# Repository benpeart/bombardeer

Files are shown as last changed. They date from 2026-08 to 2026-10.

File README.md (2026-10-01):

# Bombardeer Wildlife Deterrent Turret: System Architecture Specification

**Bombardeer** is an open-source, vision-guided autonomous deterrent turret designed to protect outdoor spaces, gardens, orchards, and agricultural property from intrusive wildlife (such as deer).

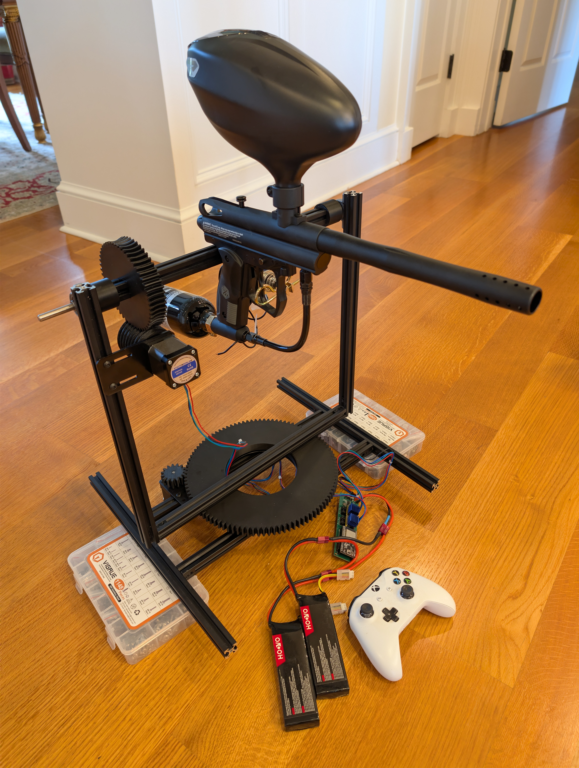
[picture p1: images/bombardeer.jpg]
Bombardeer: Autonomous Vision-Guided Deterrent Turret


Powered by a **Raspberry Pi 5** for real-time visual perception, range estimation, and dynamic parallax compensation, paired with a dedicated **ESP32** microcontroller executing hardware-timed pan/tilt motion profiles across dual TMC2209 silent stepper drivers.

---

## 🚀 Features

* **Asynchronous Perception & Motion Decoupling:** Vision inference runs at sensor rate (15–30 Hz) while a dedicated 50 Hz (20 ms tick) real-time motion servo calculates trajectory vectors, preventing camera frame drops from stalling motor actuation.

* **Segregated Lock Architecture:** Isolates concurrency across three independent lock domains (`telemetry_lock`, `target_lock`, and `frame_lock`) to eliminate lock contention, priority inversion, and serial UART stalls at 921,600 baud.

* **Forward-Projected Kalman State Estimation:** 4-state constant-velocity Kalman filter estimates 3D world-space coordinates, projecting target state forward across a fixed ~40 ms optical pipeline exposure delay directly to the actuation instant.

* **1.5-Second Dead-Reckoning Coasting:** Maintains smooth pursuit through optical occlusions, foliage, and motion blur with exponential velocity decay, avoiding target loss or abrupt stops.

* **Dual-Mode Control Hysteresis:** Seamlessly transitions between open-loop ballistic waypoint snaps (`P <pan> <tilt>`) for large angular displacements (>120 mrad) and closed-loop proportional velocity pursuit (`V <pan_s> <tilt_s>`) with 1.0× feed-forward velocity matching.

* **Dynamic Slew-Gated Solenoid Engagement:** Heschen 24V firing solenoid actuation requires optical freshness (<150 ms), verified crosshair deadband alignment (<40 mrad), and a barrel slew speed ceiling (<180 mrad/s) to prevent firing during rapid transits.

* **Software Axis Travel Clamping:** Real-time telemetry monitoring actively zeroes commanded velocity before the tilt axis can impact mechanical endstops (-420 to +400 mrad).

* **Dynamic Range Estimation & Parallax Convergence:** Computes target distance via pinhole projection (ArUco calibration or bounding-box height) and dynamically converges the bore sightline to compensate for the physical camera offset ($170\text{ mm}$ left, $60\text{ mm}$ below the bore).

* **Native Milliradian (mrad) Motion Protocol:** High-speed binary/ASCII UART link at **921,600 baud** commands velocity trims (`mrad/s`) and absolute waypoints (`mrad`), completely decoupled from hardware microstepping and gearing.

* **Precision Kinematic Reductions:**
* **Pan Axis:** Custom $6.65:1$ timing ring drive ($246\text{T} / 37\text{T}$) achieving up to $11{,}600\text{ steps/s}$ ($\approx 3{,}425\text{ mrad/s}$).
* **Tilt Axis:** Anti-backdrive $50:1$ single-start worm drive ($50\text{T} / 1\text{T}$) achieving up to $14{,}800\text{ steps/s}$ ($\approx 580\text{ mrad/s}$) with zero backdrive.

* **Dual Control Modes with Clean Handoff:** Autonomous visual pursuit over high-speed UART with seamless manual override via Bluetooth Xbox Series X/S controller integration.
* **TMC2209 UART Integration:** Dynamically manages current limits ($1200\text{ mA}$ Pan, $1100\text{ mA}$ Tilt), microstepping ($1/16$ interpolated to $1/256$), standstill `ihold` power saving, and automatic StealthChop-to-SpreadCycle transitions.

---

## 🛠️ System Architecture

```
       +-----------------------------------------------------+
       |                  Raspberry Pi 5                     |
       |  - Vision Worker (15-30 Hz PiSP / OpenCV / CLAHE)   |
       |  - Kalman Predictive State Estimator (World Space)  |
       |  - 50 Hz Motion Servoing Loop (20ms Cadence)        |
       |  - Flask Diagnostic HUD & Auto-Video Recorder       |
       +-----------------------------------------------------+
                                  |
                                  |  Bidirectional UART (921,600 Baud)
                                  |  Packets in Milliradians (mrad / mrad/s)
                                  v
       +---------------------------------------------+    +-------------------------------+
       |             ESP32 Microcontroller           |<---|   Xbox Series X Controller    |
       |  - FastAccelStepper Hardware Pulse Timer    |    |       (Bluetooth Manual)      |
       |  - Solenoid Timing State Machine            |    +---------------+---------------+
       +---------------------------------------------+
               /              |              \
              v               v               v
     +----------------+ +----------------+ +--------------------+
     | TMC2209 / Pan  | | TMC2209 / Tilt | | 24V Firing Circuit |
     | Stepper Motor  | | Stepper Motor  | | Heschen Solenoid   |
     +----------------+ +----------------+ +--------------------+

```

---

## 🧰 Hardware Requirements

| Component | Specification | Description |
| --- | --- | --- |
| **Compute Board** | Raspberry Pi 5 (8GB) | Vision pipeline, 50 Hz motion servo, Kalman prediction, HUD streaming |
| **AI Accelerator** | Hailo-8 M.2 Module (26 TOPS) | Low-latency neural network inference for real-time target detection |
| **Vision Sensor** | RPi Camera Module 3 (Wide/Standard) | $1280 \times 720$ @ $30\text{ FPS}$ low-light capture via `Picamera2`<br> |
| **Motion MCU** | ESP32-WROOM-32 | Multi-axis hardware timer pulse generation & safety watchdogs |
| **Stepper Drivers** | $2\times$ TMC2209 (v1.2+) | Single-wire UART addressing (`0b00` Pan, `0b01` Tilt) |
| **Stepper Motors** | $2\times$ STEPPERONLINE 17HS19-2004S1 | NEMA 17 ($2.0\text{A}$ Peak, $59\text{ N}\cdot\text{cm}$ Holding Torque) |
| **Pan Drive** | $6.65:1$ GT2 Timing Belt Reduction ($246\text{T} / 37\text{T}$) | High-slew azimuth tracking ($3.386\text{ steps/mrad}$) |
| **Tilt Drive** | $50:1$ Anti-Backdrive Worm Gear ($50\text{T} / 1\text{T}$) | Self-locking elevation drive ($25.465\text{ steps/mrad}$) |
| **Actuator** | Heschen HS-1564B / HS-4564B Solenoid | 24V push-pull trigger actuation ($4.0\text{ BPS}$) |
| **Mounting Offset** | $170\text{ mm}$ Left, $60\text{ mm}$ Below Bore Centerline | Baseline camera-to-barrel offset compensated in software |
| **Power Supply** | 12V–24V LiFePO4 / Battery Bank | Powers steppers, solenoid circuit, and logic step-downs |

---

## Subsystem Roles

### 1. Vision & Trajectory Planning (Raspberry Pi 5)

* **Multi-Threaded Architecture:** Clamps OpenCV to 2 dedicated physical cores, preserving remaining CPU cores for 50 Hz motion servo timing, PiSP DMA frame transfers, and serial I/O.

* **Lock Segregation:**
* `telemetry_lock`: Protects high-speed motor angles, movement flags, and historical telemetry deques.

* `target_lock`: Protects vision coordinates, target bounding boxes, disk metrics, and supervisory alerts.

* `frame_lock`: Protects JPEG buffers for the Flask diagnostic web stream.

* **Optical Intrinsics & Parallax Compensation:** Native $1280 \times 720$ capture with $f = 540.4\text{ px}$ ($1.850\text{ mrad/px}$). Calibrated trigonometric parallax adjustment aligns the barrel at range $D$ (in millimeters):

$$\Delta \theta_{\text{pan}} = \frac{-\text{OffsetX}}{D} \times 1000 = \frac{170\text{ mm}}{D} \times 1000 \quad [\text{mrad}]$$

$$\Delta \theta_{\text{tilt}} = \frac{\text{OffsetY}}{D} \times 1000 = \frac{-60\text{ mm}}{D} \times 1000 \quad [\text{mrad}]$$

* **Dynamic Firing Gate:** Actuation signals (`T 1`) are only transmitted if the target is fresh (<150 ms), radial aim error is $\le 40\text{ mrad}$, and total barrel slew speed is $<180\text{ mrad/s}$.

* **Autonomous Archival Recording:** Automatic rolling video buffer records 2.0 seconds of pre-lock context and 3.0 seconds of post-roll context upon confirmed target engagement, with automatic disk-space quota recycling.

### 2. Motion & Actuation Engine (ESP32)

* **Hardware Motion Profiler:** `FastAccelStepper` dynamically executes trapezoidal acceleration profiles on ESP32 hardware timer interrupts ($13{,}500\text{ steps/s}^2$ Pan, $50{,}000\text{ steps/s}^2$ Tilt).
* **Milliradian-to-Step Translation:** Converts incoming integer milliradians directly to stepper motor step coordinates using compile-time geometric ratios:

$$\text{Pan Steps} = \text{Angle [mrad]} \times \left(\frac{3200 \times (246 / 37)}{2000\pi}\right) \approx \text{Angle [mrad]} \times 3.3863$$

$$\text{Tilt Steps} = \text{Angle [mrad]} \times \left(\frac{3200 \times (50 / 1)}{2000\pi}\right) \approx \text{Angle [mrad]} \times 25.4648$$

* **Driver Control:** Dual TMC2209 silent stepper drivers managed over a shared single-wire UART bus (`Serial2`) with read-back validation, register reset auto-recovery, and dynamic hybrid StealthChop/SpreadCycle transitions.
* **Actuation State Machine:** Hardware-timed driver managing the Heschen firing solenoid ($60\text{ ms}$ pulse / $190\text{ ms}$ cooldown) with a hard autonomous firing cutoff of $2000\text{ ms}$.

* **Safety & Manual Override:** Dedicated `processXboxOverride()` routine handling Bluetooth input from an Xbox Series X controller with fail-safe zeroing on disconnect, quadratic stick shaping, and a single-shot 'A' button to reset coordinate origin to $(0, 0)\text{ mrad}$.

---

## Serial Communication Interface

Communication operates over UART at **921,600 baud, 8N1**, utilizing plain ASCII newline-terminated strings (`\n`).

### Commands: Raspberry Pi -> ESP32

| Command | Arguments | Unit | Description | Example |
| --- | --- | --- | --- | --- |
| `P` | `<pan> <tilt>` | `mrad` | **Ballistic Setpoint:** Absolute waypoint jump with 400 ms rate limit and 60 mrad delta lockout. | `P 280 -65` |
| `V` | `<pan_s> <tilt_s>` | `mrad/s` | **Velocity Pursuit:** Continuous speed tracking vector (up to $\pm 850\text{ pan}$, $\pm 450\text{ tilt}$). | `V 320 -85` |
| `X` | *none* | — | **Halt:** Commands immediate controlled deceleration to stop and hold position. | `X` |
| `T` | `<state: 0/1>` | flag | **Trigger:** Commands the solenoid firing state machine (`1` = fire, `0` = disengage). | `T 1` |
| `H` | *none* | — | **Home:** Stops motion and re-zeros current motor coordinates to $(0, 0\text{ mrad})$. | `H` |
| `Q` | *none* | — | **Status Query:** Requests an immediate diagnostic telemetry packet. | `Q` |

### Telemetry: ESP32 -> Raspberry Pi

| Packet | Arguments | Unit | Description | Example |
| --- | --- | --- | --- | --- |
| `S` | `<time> <pan> <tilt> <firing> <moving>` | `us`, `mrad`, `mrad`, `flag`, `flag` | **Periodic State (20–50 Hz):** Broadcasts timestamp, axis angles, firing state, and movement flag. | `S 1840291 195 45 0 1` |
| `R` | `<is_moving> <pan> <tilt>` | `flag`, `mrad`, `mrad` | **Query Response:** Transmitted immediately in response to `Q`. | `R 0 120 -45` |

---

## Hardware Specification & Kinematics

### Mechanical & Stepper Parameters

* **Pan Stepper:** 1.8° step angle ($200\text{ steps/rev}$), $16\times$ microstepping $\rightarrow 3{,}200\text{ native steps/rev}$.
* **Tilt Stepper:** 1.8° step angle ($200\text{ steps/rev}$), $16\times$ microstepping $\rightarrow 3{,}200\text{ native steps/rev}$.
* **Gear Ratios:**
* Pan: $246\text{T} / 37\text{T} \approx 6.6486:1$
* Tilt: $50\text{T} / 1\text{T} = 50:1$ (worm drive)

* **Speed Ceilings:**
* Pan: $11{,}600\text{ steps/s}$ ($\approx 3{,}425\text{ mrad/s}$)
* Tilt: $14{,}800\text{ steps/s}$ ($\approx 580\text{ mrad/s}$)

* **Acceleration Ceilings:**
* Pan: $13{,}500\text{ steps/s}^2$
* Tilt: $50{,}000\text{ steps/s}^2$

* **Travel Envelopes & Software Safety Clamps:**
* Pan Envelope: Physical hard stops at $\pm 180.0^\circ$ ($\approx \pm 3{,}141\text{ mrad}$)
* Tilt Envelope: Physical travel $\pm 22.5^\circ$ ($\approx \pm 392\text{ mrad}$); software velocity clamped at **`-420 mrad` (Min)** and **`+400 mrad` (Max)**.

### Optical Calibration (RPi Camera Module 3 @ 1280x720 Native Capture)

* **Active Sensor Resolution:** $1280 \times 720$ pixels

* **Focal Length ($f_x, f_y$):** $540.4\text{ pixels}$

* **Optical Scale Factor:** $1.850\text{ mrad/pixel}$ ($1000 / 540.4$)

* **Optical Center:** $(c_x, c_y) = (640, 360)\text{ px}$

* **Latency Compensation Offset:** Fixed $40\text{ ms}$ history interpolation window for sensor exposure and ISP DMA transfer.

---

## 🕹️ Xbox Controller Manual Override

Manual input automatically overrides autonomous targeting, locking out serial velocity commands until $400\text{ ms}$ after stick release:

* **Left Stick (Horizontal):** Pan axis continuous velocity jog (quadratic curve shaping).
* **Left Stick (Vertical):** Tilt axis continuous velocity jog (quadratic curve shaping).
* **Right Trigger (RT):** Manually trips the solenoid actuator state machine.
* **'A' Button:** Single-shot command that immediately brings both axes to a controlled halt and re-zeroes coordinate tracking to $(0, 0)\text{ mrad}$.

---

## ⚠️ Safety Disclaimer

This project is intended strictly for agricultural property management and wildlife deterrence. Ensure all hardware deployment complies with local ordinances regarding non-lethal wildlife management. Always verify hardware safety stops and clear line-of-sight before arming the turret.

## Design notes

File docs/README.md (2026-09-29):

# 🎯 Bombardeer: Autonomous Vision-Guided Deterrent Turret

**Bombardeer** is an open-source, vision-guided autonomous deterrent turret designed to protect outdoor spaces, gardens, orchards, and agricultural property from intrusive wildlife (such as deer).

Powered by a **Raspberry Pi 5** running low-latency predictive visual servoing with libcamera/Picamera2 and an **ESP32** dedicated microcontroller executing hardware-timed, trapezoidal motion profiles across dual TMC2209 stepper drivers.

---

## 🚀 Key Features

* **Native Milliradian (mrad) Kinematic Abstraction:** Complete decoupling between vision processing and hardware execution. The host sends commands in angular space (`mrad` and `mrad/s`), while the ESP32 internally manages motor microstepping, gear ratios, and acceleration envelopes.

* **Dynamic Range Estimation & Parallax Convergence:** Automatically calculates target distance using pinhole geometry (ArUco markers in test mode, bounding box height for white-tailed deer in production) and converges the physical barrel sightline (offset by 170 mm left and 60 mm below the bore).

* **Precision Kinematic Motion:**
* **Pan Axis:** Custom $6.65:1$ timing ring drive ($246\text{T} / 37\text{T}$), benchmarked at $11,600\text{ steps/s}$ ($~3,425\text{ mrad/s}$) and $13,500\text{ steps/s}^2$.

* **Tilt Axis:** Low-inertia, anti-backdrive $50:1$ single-start worm drive ($50\text{T} / 1\text{T}$), benchmarked at $14,800\text{ steps/s}$ ($~580\text{ mrad/s}$) and $50,000\text{ steps/s}^2$.

* **Hardware-Timed Step Generation:** ESP32 hardware timer engine (`FastAccelStepper`) driving TMC2209 drivers with StealthChop standstill quieting and dynamic high-speed torque transitions.

* **Dual Control Architecture with Seamless Handoff:**
* **Autonomous Visual Servoing:** Closed-loop PD velocity tracking with slew-rate limiting to eliminate overshoot and motor stalls.

* **Manual Bluetooth Override:** Xbox Series X/S controller integration with quadratic stick response curves, auto-timeout failsafes, and single-shot coordinate re-zeroing.

* **Solenoid Trigger Pulse Sequencer:** Non-blocking state machine governing a Heschen HS-1564B actuator ($60\text{ ms}$ pulse / $190\text{ ms}$ cooldown; $4.0\text{ BPS}$ cycle) with hardware runtime watchdogs.

* **Integrated Web Diagnostic HUD:** Real-time Flask streaming interface at $640 \times 360$ showing optical center crosshairs, dynamic bore-convergence impact markers, live telemetry, and automated event video recording.

---

## 🛠️ System Architecture

```
                                                 +-------------------------------+
                                                 |   Xbox Series X Controller    |
                                                 |       (Bluetooth Manual)      |
                                                 +---------------+---------------+
                                                                 |
                                                                 v
+-----------------------+     UART (921600 Baud)     +-----------------------+
|    Raspberry Pi 5     |--------------------------->|    ESP32 Controller   |
|   (Picamera2 / HUD)   |   mrad / mrad/s Commands   |   (FastAccelStepper)  |
+-----------------------+<---------------------------+-----------+-----------+
                          20 Hz Telemetry (S line)               |
                                                         UART / Step / Dir
                                                                 |
                                                                 v
                                                     +-----------------------+
                                                     |  Dual TMC2209 Drivers |
                                                     +-----------+-----------+
                                                                 |
                                                            4-Wire Stepper
                                                                 |
                                                                 v
                                                     +-----------------------+
                                                     | STEPPERONLINE NEMA 17 |
                                                     |   Pan & Tilt Motors   |
                                                     +-----------------------+

```

---

## 🧰 Hardware Specifications

| Component | Specification | Function |
| --- | --- | --- |
| **Host Computer** | Raspberry Pi 5 (8GB) | Target tracking, HUD streaming, telemetry logging |
| **Vision Sensor** | RPi Camera Module 3 (Wide/Standard) | $1280 \times 720$ @ $30\text{ FPS}$ low-light capture crop |
| **Motion MCU** | ESP32-WROOM-32 | Hardware-timed pulse generation & safety watchdogs |
| **Stepper Drivers** | $2\times$ TMC2209 (v1.2+) | Single-wire UART addressing (`0b00` Pan, `0b01` Tilt) |
| **Stepper Motors** | $2\times$ STEPPERONLINE 17HS19-2004S1 | NEMA 17 ($2.0\text{A}$, $59\text{ N}\cdot\text{cm}$ torque) |
| **Pan Drive** | $6.65:1$ GT2 Belt Reduction ($246\text{T} / 37\text{T}$) | High-slew azimuth tracking ($3.386\text{ steps/mrad}$) |
| **Tilt Drive** | $50:1$ Anti-Backdrive Worm Gear ($50\text{T} / 1\text{T}$) | Self-locking elevation drive ($25.465\text{ steps/mrad}$) |
| **Actuator** | Heschen HS-1564B / HS-4564B Solenoid | Push-pull trigger actuation |
| **Camera Offset** | $170\text{ mm}$ Left, $60\text{ mm}$ Below Bore Centerline | Baseline geometry compensated via dynamic parallax |

---

## 📡 Serial Communication Protocol (Pi 5 $\leftrightarrow$ ESP32)

Communication operates over UART at **`921600` baud (8N1)** using non-blocking, zero-allocation newline-terminated frames (`\n`).

### Host Commands (Pi 5 $\rightarrow$ ESP32)

| Command | Format | Description |
| --- | --- | --- |
| **Velocity Trim** | `V <pan_mrad_s> <tilt_mrad_s>` | Dynamic continuous slew velocity trim |
| **Relative Move** | `M <d_pan_mrad> <d_tilt_mrad>` | Discrete positional waypoint displacement |
| **Emergency Halt** | `X` | Controlled dynamic braking to a full stop |
| **Set Coordinate Zero** | `H` | Resets current physical positions to mechanical $(0, 0)$<br> |
| **State Query** | `Q` | Returns immediate motion state and coordinates |
| **Fire Trigger** | `T <0`\|`1>` | Arms/pulses or disengages autonomous firing |

### Telemetry Broadcast (ESP32 $\rightarrow$ Pi 5)

The ESP32 broadcasts status every $50\text{ ms}$ ($20\text{ Hz}$):

`S <pan_mrad> <tilt_mrad> <firing_active> <moving>`

* **`pan_mrad`**: Current pan position in milliradians relative to home zero.

* **`tilt_mrad`**: Current tilt position in milliradians relative to home zero.

* **`firing_active`**: `1` if the solenoid is actively in a firing pulse or cooldown cycle, otherwise `0`.

* **`moving`**: `1` if either stepper axis is actively stepping, otherwise `0`.

---

## 🕹️ Xbox Controller Mapping & Manual Override

When manual input is detected, the ESP32 automatically locks out incoming autonomous serial velocity commands for $400\text{ ms}$ post-input.

| Control | Action | Function |
| --- | --- | --- |
| **Left Stick (Horizontal)** | Pan Axis | Dynamic velocity slewing (quadratic precision curve) |
| **Left Stick (Vertical)** | Tilt Axis | Dynamic velocity slewing (quadratic precision curve) |
| **Right Trigger (RT)** | Solenoid Fire | Engages trigger pulse state machine |
| **A Button** | Re-Zero Home | Instantly halts motion and resets coordinates to $(0, 0)\text{ mrad}$<br> |

---

## 🖥️ Web Diagnostic Console

The Python harness provides a lightweight web streaming HUD on port `5000`:

* **Live Stream:** Displays the real-time $640 \times 360$ annotated video feed with optical center crosshairs, target bounding boxes, and projected impact markers.

* **Boresight Alignment:** Renders the dynamic point of aim (red crosshair) converged to match target distance, accounting for camera parallax.

* **Live Telemetry Banner:** Displays streaming sensor FPS, live physical coordinates, serial packet counters, and storage status.

* **Event Recording:** Pre-roll buffer captures and stores MP4 video recordings of target engagement events automatically.

Access the dashboard by navigating to:
`http://<raspberry-pi-ip>:5000/`

---

## ⚠️ Safety Disclaimer

This project is designed and intended strictly for non-lethal wildlife deterrence and agricultural property management. Always verify physical travel limits, confirm the solenoid cycle parameters, ensure lines of sight are completely clear of bystanders, and comply with all applicable local regulations regarding autonomous and non-lethal deterrent devices.

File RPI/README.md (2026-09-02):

# Raspberry Pi 5 Setup Guide: Bombardeer Vision System

This document provides the verified, clean deployment guide for setting up the Raspberry Pi 5 hardware, PCIe Gen 3 acceleration, Hailo-8 runtime, camera ISP pipelines, and web HUD streaming interface for the Bombardeer project using the assets in this repository.

---

### Hardware Requirements

* **SBC:** Raspberry Pi 5 (Active Cooler recommended)
* **AI Accelerator:** Hailo-8 M.2 Module mounted via M.2 HAT+
* **Camera:** Raspberry Pi Camera Module 3 (IMX708 NoIR / Wide) connected to `CAM/DISP 0` or `1`
* **OS:** Raspberry Pi OS 64-bit (Debian 12 Bookworm / Linux Kernel 6.12+)
* **Default User:** `ben`

---

### Step 1: Base OS Update & Camera Verification

Update the system packages:

```bash
sudo apt update && sudo apt full-upgrade -y

```

Verify that the kernel and the Raspberry Pi Image Signal Processor (PiSP) recognize the camera sensor:

```bash
rpicam-hello --list-cameras

```

*Expected detection:* Camera detected as `imx708` or `imx708_wide_noir` on `/base/axi/pcie@...`.

---

### Step 2: Enable PCIe Gen 3 Hardware Link

Raspberry Pi OS limits the single PCIe lane to Gen 2 (5 GT/s) by default. Enable PCIe Gen 3 (8 GT/s) to ensure uninterrupted data transfer:

```bash
# Append Gen 3 parameter to firmware boot config
echo "dtparam=pciex1_gen=3" | sudo tee -a /boot/firmware/config.txt

# Reboot to renegotiate the hardware link
sudo reboot

```

After the Pi boots back up, confirm the link negotiated at 8 GT/s:

```bash
sudo lspci -vv -d 1e60: | grep -i "LnkSta:"

```

*Required output:* `LnkSta: Speed 8GT/s, Width x1 (downgraded)`

---

### Step 3: Install HailoRT & Python Runtime Dependencies

Install the official Hailo-8 kernel drivers, runtime CLI, Python platform bindings, and system web packages using the Debian package manager:

```bash
# 1. Install Hailo runtime and PCIe kernel driver
sudo apt install -y hailofw hailo-all

# 2. Install computer vision and web server runtime
sudo apt install -y python3-pip python3-flask python3-opencv python3-numpy python3-picamera2

# 3. Ensure picamera2 is present and up to date
sudo apt install -y python3-picamera2

```

Verify that the Hailo PCIe driver is loaded and the NPU responds:

```bash
hailortcli fw-control identify

```

---

### Step 4: Clone the Repository

Clone your repository into the user's home folder:

```bash
cd ~
git clone <YOUR_GIT_REPO_URL> Bombardeer
cd ~/Bombardeer

```

---

### Step 5: Verify Model Benchmark on Hardware

Test the pre-compiled `MDV6-yolov9-c.hef` on the Hailo-8 NPU to ensure proper hardware allocation:

```bash
hailortcli benchmark ~/Bombardeer/models/MDV6-yolov9-c.hef

```

*Expected baseline performance:*

* **Throughput:** ~`24.66 FPS`
* **Hardware Latency:** ~`37.7 ms`

---

### Step 6: Install & Enable the Systemd Auto-Start Service

Install the service file included in the repository so the vision system starts automatically on boot:

```bash
# 1. Copy service file into systemd
sudo cp ~/Bombardeer/systemd/bombardeer.service /etc/systemd/system/

# 2. Reload daemon, enable on boot, and start immediately
sudo systemctl daemon-reload
sudo systemctl enable bombardeer.service
sudo systemctl start bombardeer.service

```

Check service status to verify the camera and NPU streams initialized cleanly:

```bash
sudo systemctl status bombardeer.service

```

---

### Step 7: Access the Live HUD

From any computer or smartphone on the local network, open a web browser and visit:

```text
http://turret.local:5000

```

*(or via IP: `[http://192.168.2.199:5000](http://192.168.2.199:5000)`)*

The HUD interface will display:

* Live 640×640 camera stream processed directly by the Raspberry Pi hardware ISP.
* Centered crosshairs at optical zero `(320, 320)`.
* Green bounding boxes around detected animals with tracking displacement vectors `(dx, dy)`.
* **Bombardeer** custom favicon in your browser tab.
* Sustained ~24.6 FPS execution across all 4 Hailo-8 hardware contexts.

To follow real-time detection telemetry and tracking offsets in your terminal:

```bash
journalctl -u bombardeer.service -f

```

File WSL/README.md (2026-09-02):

This complete end-to-end guide details how to take a fresh WSL2 environment on Windows, set up the Dockerized Hailo AI Software Suite with NVIDIA GPU acceleration, optimize MegaDetector v6 (YOLOv9-c), and compile the binary `MDV6-yolov9-c.hef` for execution on the Raspberry Pi 5 Hailo-8 NPU.

---

### Prerequisites & Architecture

* **Host Machine:** Windows 10/11 with WSL2 (Ubuntu), NVIDIA GPU (e.g., RTX 40-series), and current NVIDIA drivers installed on Windows.
* **Target Hardware:** Raspberry Pi 5 with Hailo-8 M.2 AI HAT.
* **Model:** MegaDetector v6 Compact (`MDV6-yolov9-c.onnx`, $640\times640$ input, 3 classes: Animal, Person, Vehicle).

---

### Step 1: Prepare the WSL2 Host Environment

Open PowerShell as Administrator to ensure WSL2 is up to date:

```powershell
wsl --update

```

Open your WSL Ubuntu terminal and install Docker CE, the NVIDIA Container Toolkit, and build tools:

```bash
# 1. Update system packages
sudo apt update && sudo apt install -y curl gnupg lsb-release wget ca-certificates

# 2. Install Docker Engine
sudo install -m 0755 -d /etc/apt/keyrings
curl -fsSL https://download.docker.com/linux/ubuntu/gpg | sudo gpg --dearmor -o /etc/apt/keyrings/docker.gpg
sudo chmod a+r /etc/apt/keyrings/docker.gpg

echo \
  "deb [arch=$(dpkg --print-architecture) signed-by=/etc/apt/keyrings/docker.gpg] https://download.docker.com/linux/ubuntu \
  $(lsb_release -cs) stable" | sudo tee /etc/apt/sources.list.d/docker.list > /dev/null

sudo apt update
sudo apt install -y docker-ce docker-ce-cli containerd.io docker-buildx-plugin docker-compose-plugin

# 3. Add current user to Docker group & start service
sudo usermod -aG docker $USER
sudo service docker start

# 4. Install NVIDIA Container Toolkit (for GPU passthrough into Docker)
curl -fsSL https://nvidia.github.io/libnvidia-container/gpgkey | sudo gpg --dearmor -o /usr/share/keyrings/nvidia-container-toolkit-keyring.gpg \
  && curl -s -L https://nvidia.github.io/libnvidia-container/stable/deb/nvidia-container-toolkit.list | \
    sed 's#deb https://#deb [signed-by=/usr/share/keyrings/nvidia-container-toolkit-keyring.gpg] https://#g' | \
    sudo tee /etc/apt/sources.list.d/nvidia-container-toolkit.list

sudo apt update
sudo apt install -y nvidia-container-toolkit
sudo nvidia-ctk runtime configure --runtime=docker
sudo service docker restart

```

Verify GPU availability within Docker:

```bash
docker run --rm --gpus all nvidia/cuda:12.0.0-base-ubuntu22.04 nvidia-smi

```

---

### Step 2: Set Up the Persistent Shared Workspace

Create a dedicated workspace folder on your WSL host that will remain mounted inside the container:

```bash
mkdir -p ~/hailo/shared_with_docker
cd ~/hailo

```

Download the official Hailo AI Software Suite Docker image archive (e.g., `hailo8_ai_sw_suite_2026-07.zip` or `.tar.gz`) from the [Hailo Developer Zone](https://hailo.ai/developer-zone/) into `~/hailo`.

Load the Docker image (assuming the extracted image tar is present):

```bash
docker load -i hailo8_ai_sw_suite_2026-07.tar

```

---

### Step 3: Run the GPU-Accelerated Hailo Suite Container

Launch the container with full compute/utility driver capabilities and mount your shared directory:

```bash
docker run --gpus 'all,"capabilities=compute,utility"' \
  -e NVIDIA_VISIBLE_DEVICES=all \
  -e NVIDIA_DRIVER_CAPABILITIES=compute,utility \
  --privileged --net=host -e DISPLAY=:0 \
  --ipc=host --group-add 44 \
  -v /dev:/dev -v /lib/firmware:/lib/firmware -v /lib/modules:/lib/modules \
  -v /lib/udev/rules.d:/lib/udev/rules.d -v /usr/src:/usr/src \
  --name hailo8_ai_sw_suite_container \
  -v $HOME/hailo/shared_with_docker/:/local/shared_with_docker:rw \
  -ti hailo8_ai_sw_suite_2026-07:latest

```

---

### Step 4: Configure Container Environment & cuDNN

Inside the container shell `(hailo_virtualenv) hailo@...:/local/workspace$`:

1. **Configure dynamic library and GPU ID variables:**
```bash
cat << 'EOF' >> ~/.bashrc
export CUDNN_PATH=$(python3 -c "import nvidia.cudnn; print(list(nvidia.cudnn.__path__)[0] + '/lib')" 2>/dev/null)
export LD_LIBRARY_PATH=$CUDNN_PATH:$LD_LIBRARY_PATH
export CUDA_VISIBLE_DEVICES=0
export HAILO_GPU_ID=0
EOF

source ~/.bashrc

```

2. **Verify GPU detection:**
```bash
hailo --version

```

*(Ensure no fallback warnings appear and cuBLAS/cuDNN initialize).*
3. **Navigate to the shared directory:**
```bash
cd /local/shared_with_docker

```

---

### Step 5: Acquire the ONNX Model & Generate Calibration Data

1. **Download the official MegaDetector v6 YOLOv9-c ONNX model:**
```bash
wget -O MDV6-yolov9-c.onnx "https://zenodo.org/records/15398270/files/MDV6-yolov9-c.onnx?download=1"

```

2. **Generate Calibration Dataset (`calib_data.npy`):**
The Dataflow Compiler requires a calibration set matching the input layer dimensions: 64 to 128 images of shape `(N, 640, 640, 3)` with `uint8` values $[0, 255]$.
```bash
python3 -c "
import numpy as np
# Generate 64 calibration frames matching 640x640x3 RGB
calib = np.random.randint(0, 256, size=(64, 640, 640, 3), dtype=np.uint8)
np.save('calib_data.npy', calib)
print('Created calib_data.npy:', calib.shape, calib.dtype)
"

```

*(Note: You can replace random noise with real pasture/camera images resized to $640\times640\times3$ for marginally tighter quantization SNR).*

---

### Step 6: Parse the ONNX Model into Hailo Archive (HAR)

Run the parser with an explicit input shape. Supply `"y"` to accept the recommended YOLO detection heads:

```bash
printf "y\ny\n" | hailo parser onnx MDV6-yolov9-c.onnx \
  --hw-arch hailo8 \
  --start-node-names images \
  --tensor-shapes [1,3,640,640] \
  --har-path MDV6_yolov9_c.har

```

This extracts the three scale heads:

* Stride 8: `conv98` ($80\times80\times64$) & `conv100` ($80\times80\times3$)
* Stride 16: `conv121` ($40\times40\times64$) & `conv122` ($40\times40\times3$)
* Stride 32: `conv143` ($20\times20\times64$) & `conv144` ($20\times20\times3$)

---

### Step 7: Quantize and Optimize

Create the compiler script configuring input normalization and maximum performance tuning:

```bash
cat << 'EOF' > mdv6.alls
normalization1 = normalization([0.0, 0.0, 0.0], [255.0, 255.0, 255.0])
performance_param(compiler_optimization_level=max)
EOF

```

Run the quantizer (leveraging the GPU for cuDNN bias correction and SNR noise analysis):

```bash
hailo optimize MDV6_yolov9_c.har \
  --calib-set-path calib_data.npy \
  --model-script mdv6.alls \
  --output-har-path MDV6_yolov9_c_quantized.har

```

---

### Step 8: Compile to Hardware Execution Format (HEF)

Run the compiler to execute graph partitioning and cluster resource allocation:

```bash
hailo compiler MDV6_yolov9_c_quantized.har

```

* Graph partitioning runs across CPU cores using an Integer Linear Programming (ILP) solver.
* The compiler will split the model into **4 contexts** to map within the Hailo-8's on-chip SRAM clusters without DDR thrashing.
* Upon completion, `MDV6-yolov9-c.hef` will be written directly to `/local/shared_with_docker/`.

---

### Step 9: Inspect the Resulting Binary

Verify the compiled binary stream configuration:

```bash
hailortcli parse-hef /local/shared_with_docker/MDV6-yolov9-c.hef

```

Confirm the following output structure:

* **Architecture:** `HAILO8`
* **Contexts:** `4`
* **Input:** `MDV6-yolov9-c/input_layer1 UINT8, NHWC(640x640x3)`
* **Outputs:** 6 regression/class tensors across strides 8, 16, and 32.

---

### Step 10: Deploy and Benchmark on the Raspberry Pi 5

Exit the container to return to your WSL host prompt:

```bash
exit

```

Transfer the HEF from your persistent directory to the Pi:

```bash
scp ~/hailo/shared_with_docker/MDV6-yolov9-c.hef ben@turret.local:~/Bombardeer/

```

SSH into your Pi 5 and run the hardware benchmark:

```bash
ssh ben@turret.local "hailortcli benchmark ~/Bombardeer/MDV6-yolov9-c.hef"

```

Expected operational baseline:

* **Throughput:** ~**24.66 FPS**
* **Hardware Latency:** ~**37.7 ms**
* **Inference Mode:** Multi-context streaming across PCIe Gen 3.

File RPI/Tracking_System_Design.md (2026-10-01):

### System Architecture & Operational Pipeline

The Bombardeer tracking system coordinates optical perception, predictive state estimation, and physical motor actuation across three distinct layers.

---

### 1. Asynchronous Perception and Motion Decoupling

Rather than running in a single sequential loop, the system decouples computer vision from motor control into independent threads:

* **Vision Pipeline (Sensor-Rate, ~30 Hz):** Captures video frames, detects optical markers, estimates target range, and translates pixel positions into physical milliradian coordinates relative to the bore axis.

* **Motion Servoing Loop (Deterministic 50 Hz, 20 ms ticks):** Operates on an uninterrupted hardware timer, calculating real-time error vectors and streaming velocity commands to the ESP32 microcontroller.

Decoupling ensures that camera frame drops, auto-exposure adjustments, or vision processing latency never starve the motor servo or introduce trajectory jitter.

---

### 2. Latency Compensation via Kalman State Estimation

Image sensor exposure, image transfer, and computer vision processing introduce a measurement lag of approximately 30–50 ms. Steering directly toward raw vision coordinates causes steady-state pursuit lag behind moving targets.

* A 4-state Kalman filter models target position and velocity in world space.

* On every 20 ms tick, the filter projects the target's trajectory forward to the exact instant of actuation.

* Feed-forward velocity terms allow the turret to match target speed directly, driving positional error toward zero even during fast lateral sweeps.

---

### 3. Dual-Mode Control Strategy

The motion servo switches between two control modes based on angular displacement:

* **Mode 1: Ballistic Snap (`P` Command):** When the angular error exceeds 120 mrad (~6.9°), the controller commands an open-loop acceleration trajectory directly to the predicted coordinate. Setpoint rate-limiting locks out redundant commands during transit, preventing trajectory replanning overhead on the stepper driver.

* **Mode 2: Continuous Pursuit (`V` Command):** Once the target enters the tracking envelope, the system transitions to continuous proportional-derivative velocity control. The motor speeds are modulated at 50 Hz to smoothly track the target without stopping and starting.

---

### 4. Dead-Reckoning Coasting Horizon

To handle visual occlusions, motion blur, and lighting dropouts, the system maintains a 1.5-second dead-reckoning window:

* If the visual target is lost, the Kalman filter continues projecting target coordinates based on its last known velocity.

* After 350 ms of sustained dropout, commanded motor speeds decay exponentially toward zero over the remainder of the 1.5-second window.

* If optical detection resumes before timeout, tracking continues smoothly; otherwise, the system zeroes velocity and idles in standby.

---

### 5. Hardware Safety & Firing Enforcement

Physical constraints and firing logic are governed by strict operational gates:

* **Travel Limits:** Real-time telemetry monitoring prevents velocity commands from driving the elevation axis past mechanical limits.

* **Dynamic Firing Criteria:** Solenoid trigger pulses require three conditions simultaneously: optical data must be fresh (<150 ms), radial aim error must fall inside the 40 mrad engagement envelope, and overall turret slew speed must be below 180 mrad/s to avoid firing during rapid slewing.

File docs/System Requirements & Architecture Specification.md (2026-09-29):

# System Requirements & Architecture Specification: Bombardeer Autonomous Turret

## 1. System Summary

Build a two-tier, fault-tolerant autonomous target-tracking and deterrent turret system called **Bombardeer**. The system distributes compute tasks across a **Raspberry Pi (Host Vision & Target Policy)** and an **ESP32 (Hardware Real-Time Motion Control & Actuation)** linked via high-speed USB-UART.

The system tracks visual targets (ArUco markers / future object models), maps image-space coordinate errors into real-world milliradians, and commands atomic waypoints (`P`) for the ESP32 to execute using smooth hardware-timed trapezoidal acceleration profiles.

---

## 2. Hardware Architecture & Pinout Requirements

### 2.1 Microcontrollers & Connectivity

* **Host Processor:** Raspberry Pi 5 running Linux.

* **Motion Controller:** ESP32 NodeMCU / DevKit V1.

* **Host-Controller Bus:** USB-UART via `/dev/ttyUSB0` (or `/dev/ttyACM0`) operating at **921,600 baud, 8N1**.

* **Driver Bus:** Dedicated ESP32 `Serial2` hardware UART for TMC2209 driver communication operating at **115,200 baud**.

### 2.2 ESP32 Pin Allocation

* **Pan Stepper Driver (TMC2209 Address `0b00`):**
* `STEP`: GPIO 26

* `DIR`: GPIO 25

* `USTEP1` (MS1): GPIO 04 (Tied to GND/LOW)

* `USTEP2` (MS2): GPIO 27 (Tied to GND/LOW)

* **Tilt Stepper Driver (TMC2209 Address `0b01`):**
* `STEP`: GPIO 33

* `DIR`: GPIO 32

* `USTEP1` (MS1): GPIO 18 (Tied to VCC/HIGH)

* `USTEP2` (MS2): GPIO 05 (Tied to GND/LOW)

* **Shared Stepper Enable:** GPIO 19 (Active LOW).

* **TMC2209 Single-Wire Half-Duplex Bus:**
* `TMC_RX`: GPIO 16 (ESP32 RX2 connected directly to TMC2209 UART pin).

* `TMC_TX`: GPIO 17 (ESP32 TX2 connected through a $1\text{ k}\Omega$ series resistor to the same single-wire line).

* **Solenoid Actuator Output:** GPIO 13 (Drives logic-level MOSFET / relay circuit).

### 2.3 Stepper Motors & Mechanical Transmission

* **Motors:** 1.8° NEMA 17 steppers (200 full steps/rev, 16 microsteps $\to$ 3,200 steps/motor rev).

* **Angular Units:** Native milliradians ($1\text{ full rev} = 2000\pi \approx 6283.1853\text{ mrad}$).

* **Pan Axis:**
* Ring Gear: 246 teeth; Pinion Gear: 37 teeth (Gear ratio $\approx 6.6486:1$).

* Resolution: $\approx 3.386\text{ steps/mrad}$ ($\approx 0.295\text{ mrad/step}$).

* Software Limits: $\pm 180.0^\circ$ ($\pm 3141\text{ mrad}$).

* **Tilt Axis:**
* Worm Gear: 50 teeth; Worm: 1 start (Gear ratio: $50.0:1$).

* Resolution: $\approx 25.465\text{ steps/mrad}$ ($\approx 0.039\text{ mrad/step}$).

* Software Limits: $\pm 22.5^\circ$ ($\pm 392\text{ mrad}$).

### 2.4 Sensor & Optical Alignment

* **Camera:** Raspberry Pi Camera Module 3 Wide (IMX708 NoIR).

* **Intrinsics:** Native frame resolution 1280x720, focal length $f \approx 540.4\text{ px}$.

* **Bore-to-Sensor Parallax Offsets:**
* Camera X Offset: $-170.0\text{ mm}$ (Camera is mounted 170 mm left of bore axis).

* Camera Y Offset: $-60.0\text{ mm}$ (Camera is mounted 60 mm below bore axis).

---

## 3. ESP32 Firmware Requirements (`main.cpp`)

### 3.1 Motion Engine

* Must use `FastAccelStepper` for jitter-free, hardware-timer step generation.

* Configure Pan acceleration to 13,500 steps/s² and max speed to 11,600 Hz.

* Configure Tilt acceleration to 50,000 steps/s² and max speed to 14,800 Hz.

* Support atomic setpoint target updates via `moveTo()`. Calling `moveTo()` mid-transit must dynamically update the destination without stopping or interrupting motor velocity curves.

### 3.2 TMC2209 Configuration

* Initialize via `TMCStepper` library over `Serial2`.

* Configure Pan for 1200 mA RMS active current, 0.25 hold multiplier.

* Configure Tilt for 1100 mA RMS active current, 0.50 hold multiplier (critical to avoid gravity-induced cantilever droop when motors stop).

* Enable Hybrid StealthChop/SpreadCycle mode with `TPWMTHRS = 200` to maintain silent standstill while guaranteeing high-speed torque.

### 3.3 Actuator Control State Machine

* Non-blocking Heschen solenoid pulse state machine:
* `SOLENOID_PULSE_LENGTH`: 60 ms ON.

* `SOLENOID_COOLDOWN_LENGTH`: 190 ms OFF (enforces 4.0 BPS max cyclic rate).

* Hard failsafe timeout: Autonomous firing cannot exceed 2000 ms continuous duration.

### 3.4 Fallback & Overrides

* **Xbox Series X Bluetooth Controller:** Support wireless manual override via `XboxSeriesXControllerESP32_asukiaaa`. Left stick controls velocity, right trigger actuates solenoid, 'A' button sets current physical position as Home zero (`0, 0`). When manual input is detected, host serial motion commands are locked out for 400 ms.

* **Host Watchdog:** If no valid serial byte is received from the Raspberry Pi for 500 ms, automatically ramp down velocity to zero and halt all motion.

---

## 4. Communication Protocol Requirements

### 4.1 Host-to-Controller Commands (Pi $\to$ ESP32)

Lines must be ASCII strings terminated with `\n`:

* `P <pan_mrad:long> <tilt_mrad:long>\n` — Absolute position waypoint command.

* `T <state:0|1>\n` — Solenoid trigger state command.

* `X\n` — Emergency/controlled halt.

* `H\n` — Re-zero current motor positions in place.

* `Y <timestamp_pi:unsigned long>\n` — Clock-sync ping request.

### 4.2 Controller-to-Host Telemetry (ESP32 $\to$ Pi)

Broadcast continuously at **20 Hz (every 50 ms)**:

```text
S <timestamp_ms> <pan_mrad> <tilt_mrad> <firing_active> <is_moving>\n

```

* Response to `Y` must immediately echo: `Y <timestamp_pi> <esp32_now_ms>\n`.

---

## 5. Raspberry Pi Software Requirements (`bombardeer.py`)

### 5.1 Vision & Perception Pipeline

* **Engine:** `picamera2` capturing dual streams:
* Main stream: 1280x720 RGB888 native.

* Lores stream: 640x360 RGB888 for low-latency web HUD visualization.

* Preserve full 33.3 ms exposure integration window for low-light dawn/dusk sensitivity.

* **Detector:** OpenCV ArUco detector (Dictionary 4x4_50, ID 0) with CLAHE contrast enhancement.

* **Optical Mapping:** Must use **true pinhole ray projection** via `math.atan2` rather than linear pixel scaling to eliminate peripheral lens distortion:

$$\Delta x = -(x_{\text{center}} - \text{OPTICAL\_CENTER}_x) \text{[cite: 2]}$$

$$\Delta y = -(y_{\text{center}} - \text{OPTICAL\_CENTER}_y) \text{[cite: 2]}$$

$$\text{Error}_{\text{pan}} = \arctan\left(\frac{\Delta x}{f_x}\right) \times 1000 + \text{Parallax}_{\text{pan}} \text{[cite: 2]}$$

$$\text{Error}_{\text{tilt}} = \arctan\left(\frac{\Delta y}{f_y}\right) \times 1000 + \text{Parallax}_{\text{tilt}} \text{[cite: 2]}$$

* **Parallax Range Compensation:**

$$\text{Parallax}_{\text{pan}} = \left(\frac{-\text{CAMERA\_OFFSET\_X\_MM}}{\text{range\_m} \times 1000}\right) \times 1000 \text{[cite: 2]}$$

$$\text{Parallax}_{\text{tilt}} = \left(\frac{\text{CAMERA\_OFFSET\_Y\_MM}}{\text{range\_m} \times 1000}\right) \times 1000 \text{[cite: 2]}$$

### 5.2 State Estimation & Target Filtering

* **World-Space Kalman Filter:** A 4-state linear Kalman Filter tracking the target in **Global Turret Coordinates (mrad)** with dynamic $\Delta t$:

$$\vec{x} = [\text{pan}, \text{tilt}, v_{\text{pan}}, v_{\text{tilt}}]^T \text{[cite: 2]}$$

* State transition matrix adapts dynamically to frame interval $\Delta t$.

* Damps high-frequency image sensor noise ($\pm 3\text{ to }7\text{ mrad}$ baseline pixel jitter) without lagging behind target moves.

* **Motion Deadbands & Firing Policy:**
* `DEADBAND_MRAD`: $30.0\text{ mrad}$ (Once inside this error, suppress waypoint dispatching to eliminate hunting).

* `FIRE_DEADBAND_MRAD`: $40.0\text{ mrad}$ (Permit solenoid actuation only when radial error is strictly within this radius).

* Stream setpoint updates at a stable 20 Hz rate whenever radial error exceeds `DEADBAND_MRAD`.

### 5.3 Zero-Latency Serial Ingestion & Supervision

* **Buffer Drain Engine:** Must use non-blocking chunk reading (`ser.read(ser.in_waiting)`) to drain operating system serial buffers completely on each iteration, preventing queue latency buildup.

* **Hardware Reset Suppression:** On serial port initialization, explicitly clear `dtr = False` and `rts = False` to prevent spurious DTR toggling that forces the ESP32 into reset loops.

* **Non-Destructive Error Handling:** Do not call `ser.close()` on transient framing errors or string conversion exceptions; isolate parsing errors on a per-line basis.

* **Kinematic Ring Buffer:** Maintain a sliding history of physical turret positions indexed by monotonic capture timestamps to compute historical alignment during exposure.

### 5.4 Diagnostic Web Console & Auto-Archiver

* Provide a multi-threaded Flask web server on port 5000 streaming an MJPEG feed with targeting crosshairs, parallax convergence indicators, and active system telemetry.

* Automatically trigger MP4 video recording (H.264 / MP4V) upon target lock with 2.0 seconds of pre-roll and 3.0 seconds of post-roll. Ensure automated disk management purges oldest recordings if free space drops below 5.0 GB.

---

## 6. Verification Criteria & Acceptance Tests

1. **Low-Latency Serial Link:** Telemetry round-trip time (RTT) measured on the host must remain below 10.0 ms during full-speed motion.

2. **Single-Stroke Alignment:** When an off-axis target appears at $>400\text{ mrad}$ offset, the turret must calculate physical coordinates, accelerate, slew, and land inside the $30\text{ mrad}$ deadband in a single continuous movement without stuttering, overshoot, or intermediate stop-and-go steps.

3. **No Standstill Hunting:** When stationary on target, optical pixel noise must be absorbed by the Kalman filter and deadband; the turret must generate zero motor steps while holding position.

4. **Boot Stability:** The Raspberry Pi script must be capable of launching before or after the ESP32 powers on without triggering serial reset loops or unhandled exceptions.

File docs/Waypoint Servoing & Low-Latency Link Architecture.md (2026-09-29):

# Waypoint Servoing & Low-Latency Link Architecture

## 1. System Overview

The Bombardeer autonomous tracking turret distributes computing tasks across two specialized microprocessors connected over an asynchronous USB-UART link:

```
[ Raspberry Pi 5 (picamera2) ] 
       │  High-resolution optical tracking (IMX708 NoIR)
       │  Pinhole distortion correction (math.atan2)
       │  World-space target estimation & Kalman filtering
       │  Command scheduling & trigger policy
       ▼  UART: 921,600 Baud ('P <pan> <tilt>', 'T <0|1>')
[ ESP32 Motor Controller ]
       │  FastAccelStepper deterministic pulse generation
       │  TMC2209 silent stepper drivers (StealthChop/SpreadCycle)
       │  Heschen solenoid trigger pulse state machine
       │  20 Hz deterministic telemetry stream ('S <t> <p> <t> <f> <m>')
       ▼
[ Pan/Tilt Gimbals & Solenoid Actuator ]

```

The system uses absolute waypoint servoing (`P`) rather than continuous velocity nudging (`V`). The host vision system estimates the target's physical coordinates in real-world milliradians and transmits an atomic destination point. The ESP32's hardware timers execute smooth S-curve/trapezoidal acceleration profiles directly to the coordinate, eliminating transport jitter from the motion trajectory.

---

## 2. Hardware Configuration & Kinematics

### Coordinate Units & Physical Ratios

All rotational angles and errors are computed natively in **milliradians (mrad)**:

* Full Circle = $2000\pi \approx 6283.1853\text{ mrad}$

* Motors: 1.8° NEMA 17 steppers (200 full steps/rev $\times$ 16 microsteps = 3,200 steps/rev)

$$\text{Pan Ratio} = \frac{246\text{ ring teeth}}{37\text{ pinion teeth}} \approx 6.6486 \implies \text{PAN\_STEPS\_PER\_MRAD} \approx 3.386 \text{ steps/mrad} \text{[cite: 1]}$$

$$\text{Tilt Ratio} = \frac{50\text{ worm wheel teeth}}{1\text{ start}} = 50.0 \implies \text{TILT\_STEPS\_PER\_MRAD} \approx 25.465 \text{ steps/mrad} \text{[cite: 1]}$$

### Stepper Driver & Actuator Settings

* **Pan Driver (TMC2209 Address `0b00`):** 1200 mA RMS run current, 0.25–0.35 hold current multiplier.

* **Tilt Driver (TMC2209 Address `0b01`):** 1100 mA RMS run current, 0.50 hold current multiplier (prevents vertical cantilever sag on standstill).

* **UART Bus:** Single-wire half-duplex on ESP32 `Serial2` (GPIO 16 RX, GPIO 17 TX via a $1\text{ k}\Omega$ series resistor) operating at **115,200 baud**.

* **Solenoid Actuator (GPIO 13):** Heschen pull-type solenoid with a 60 ms active fire pulse followed by a 190 ms cooldown window (maximum 4.0 BPS cycle rate).

---

## 3. Communication Protocol

The host-to-controller link operates over `/dev/ttyUSB0` at **921,600 baud, 8N1**.

### Host Commands (Raspberry Pi $\to$ ESP32)

* `P <pan_mrad> <tilt_mrad>\n` — Command absolute physical waypoint targets.

* `T <0|1>\n` — Set autonomous solenoid trigger state.

* `X\n` — Command immediate dynamic controlled halt and lock current steps.

* `H\n` — Zero current motor coordinates in place.

### Controller Telemetry (ESP32 $\to$ Raspberry Pi)

Broadcast deterministically at **20 Hz (every 50 ms)**:

```text
S <timestamp_ms> <pan_mrad> <tilt_mrad> <firing_active> <is_moving>\n

```

* `<timestamp_ms>`: ESP32 local clock timestamp via `millis()`.

* `<pan_mrad>`, `<tilt_mrad>`: Current physical motor coordinates calculated from step registers.

* `<firing_active>`: `1` if solenoid is energized or in fire cycle, else `0`.

* `<is_moving>`: `1` if either `FastAccelStepper` channel is actively generating step pulses, else `0`.

---

## 4. Key Engineering Challenges & Solutions

### A. OS Serial Buffer Bloat (989 ms $\to$ 2 ms Latency)

* **Problem:** In early tests, round-trip latency climbed to nearly 1,000 ms. Standard line-by-line reads (`readline()`) combined with thread sleep intervals were slower than incoming 20 Hz telemetry, causing stale serial frames to accumulate in Linux kernel buffers. The vision loop was calculating errors based on where the turret was one second in the past.
* **Solution:** Replaced line-by-line reading with a non-blocking chunk drainer (`ser.read(ser.in_waiting)`). On every worker tick, the entire hardware buffer is ingested, split into complete newline-delimited tokens, and only the newest telemetry state is latched. Telemetry round-trip latency dropped to **2.2 ms**.

### B. High-Speed Baud Mismatch & USB Auto-Reset Traps

* **Problem:** When increasing link performance, `main.cpp` was compiled at 921,600 baud while `bombardeer.py` was set to 115,200 baud. The baud rate mismatch caused telemetry frames to arrive as framing-error noise. An aggressive watchdog script misinterpreted the missing telemetry as a link drop and rapidly closed and reopened the port. On Linux, cycling `/dev/ttyUSB0` toggles the CP2102/CH340 DTR/RTS lines, grounding the ESP32 `EN` pin and throwing the hardware into an infinite bootloader reset loop.

* **Solution:** Matched the serial configuration on both ends to 921,600 baud. In Python, `ser.dtr = False` and `ser.rts = False` are asserted immediately upon opening, and the watchdog policy was converted to a soft state change rather than closing and tearing down the physical connection.

### C. Wide-Angle Peripheral Optical Distortion

* **Problem:** Using a simple linear scaling constant ($\text{error} = \Delta \text{px} \times K$) worked near the crosshairs, but introduced a 60+ mrad offset when targets appeared near the edges of the IMX708 Wide lens. The initial slew command would launch toward $+245\text{ mrad}$ when the true physical target was at $+184\text{ mrad}$, requiring multiple corrective moves to settle.
* **Solution:** Replaced small-angle linear approximations with exact pinhole ray projections:

$$\Delta x = -(x_{\text{center}} - x_{\text{optical\_center}})$$

$$\text{Error}_{\text{pan}} = \arctan\left(\frac{\Delta x}{f_x}\right) \times 1000 + \text{Parallax}_{\text{pan}}$$

This eliminated off-axis geometric distortion, allowing the primary ballistic slew to land within the target deadband on the first attempt.

### D. Sub-Pixel Noise & Deadband Hysteresis

* **Problem:** Normal camera shot noise and ArUco corner extraction jitter cause stationary targets to fluctuate by $\pm 2\text{ to }4\text{ pixels}$ ($\pm 3\text{ to }7\text{ mrad}$). Without filtering, these fluctuations repeatedly crossed the motion threshold, re-triggering small stepper adjustments and hunting.
* **Solution:** Built a 4-state constant-velocity Kalman Filter (`TargetKalmanFilter`) running in **World Milliradian Space** ($[\text{pan}, \text{tilt}, v_{\text{pan}}, v_{\text{tilt}}]^T$). Because a stationary target has an invariant world coordinate regardless of turret motion, the filter dampens high-frequency optical noise while preserving rapid response. Paired with a $30.0\text{ mrad}$ tracking deadband and a $40.0\text{ mrad}$ fire deadband, post-arrival jitter is completely ignored.

---

## 5. End-to-End Execution Trace

The following production log illustrates an acquisition, slew, deceleration, and firing sequence:

```text
12:21:52.800 [INFO] [TRACK] Cur:(  +11,+228) | Err:(-433.1,-252.2) Rad:501.2 | Goal:( -422, -24) | Mv:0
12:21:52.801 [INFO] [SERIAL TX] -> P -422 -24
12:21:52.867 [INFO] [SERIAL TX] -> P -423 -26
12:21:52.929 [INFO] [SERIAL TX] -> P -429 -32
12:21:52.952 [INFO] [TRACK] Cur:(  -20,+214) | Err:(-425.1,-257.7) Rad:497.1 | Goal:( -433, -38) | Mv:1
12:21:53.901 [INFO] [TRACK] Cur:( -429, -32) | Err:(-14.2,+11.7) Rad:18.5 | Goal:( -443, -20) | Mv:0
12:21:53.901 [INFO] [SERIAL] Solenoid trigger pulse FIRED
12:21:54.066 [INFO] [TRACK] Cur:( -429, -32) | Err:(-23.2,-1.7) Rad:23.3 | Goal:( -452, -35) | Mv:0
12:21:54.231 [INFO] [TRACK] Cur:( -429, -32) | Err:(-15.4,+7.0) Rad:16.9 | Goal:( -444, -24) | Mv:0
12:21:55.231 [INFO] [TRACK] Cur:( -429, -32) | Err:(-20.6,+1.9) Rad:20.6 | Goal:( -450, -30) | Mv:0

```

### Trace Breakdown:

1. **Target Sighting (`12:21:52.800`):** Turret is resting at `(+11, +228) mrad` with motors stationary (`Mv: 0`). Vision detects a target at $(-433.1, -252.2)\text{ mrad}$ displacement. Goal is computed as `(-422, -24) mrad`. Initial waypoint `P -422 -24` is dispatched over serial.

2. **Acceleration & Slew (`12:21:52.867 – 12:21:52.952`):** ESP32 initiates step acceleration curves. As the initial movement begins, subsequent frames refine the world-space target to `(-429, -32) mrad`. `FastAccelStepper` updates its active destination mid-stroke without interrupting motor acceleration. ESP32 reports `Mv: 1`.

3. **Ballistic Transit Window (`12:21:52.952 – 12:21:53.901`):** Turret sweeps through $409\text{ mrad}$ Pan and $246\text{ mrad}$ Tilt in ~950 ms. High-speed angular motion creates camera motion blur. The fresh-detection gate suppresses command generation during the brief optical dropout, allowing the ESP32 to track cleanly toward the designated waypoint.
4. **Touchdown & Deceleration (`12:21:53.901`):** ESP32 arrives at the target steps, halts pulse generation, and reports `Cur: (-429, -32) | Mv: 0`. Camera sharpness returns immediately. Residual optical error is measured at $(-14.2, +11.7)\text{ mrad}$ ($\text{Radial} = 18.5\text{ mrad}$).

5. **Authorization to Fire (`12:21:53.901`):** Because radial error ($18.5\text{ mrad}$) is inside `FIRE_DEADBAND_MRAD` ($40.0\text{ mrad}$), the Pi transmits the fire pulse command. The ESP32 pulls GPIO 13 high to actuate the solenoid.

6. **Stationary Lock (`12:21:54.066 – 12:21:55.231`):** Subsequent frames report optical errors fluctuating between $16.9\text{ mrad}$ and $23.3\text{ mrad}$ due to sensor noise. Because all values remain safely within `DEADBAND_MRAD` ($30.0\text{ mrad}$), no further setpoints are dispatched. The turret remains firmly on target without re-triggering corrective moves.

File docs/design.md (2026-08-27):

# Bombardeer

# Features

* Turret will automatically identify targets of interest (deer) and shoot them.  
* Need to record video of shots so we can get cool footage  
* To minimize the number of turrets needed to protect a given area, greater range is always nicer  
* Ability to track moving targets and fire on the move  
* Ability to track multiple targets and rapidly switch between them while firing  
* Remote control/view

# MVP

* Single camera, no depth calculations, no ballistics, just point and shoot at the center of the object  
* Pan and tilt to aim turret  
* Auto fire when on target  
* Implement Ring-Buffer / Event-Based Recording that will record/save video x seconds before and after firing

# Hardware Design

## Turret Base

* Need a gun mount that can point the gun in any given direction and angle (rotate left/right 180 degrees, up/down \~45 degrees?) quickly and quietly.  
  * Gun mount has pan and tilt support using [stepper motors](https://www.amazon.com/dp/B00PNEQKC0?ref=ppx_yo2ov_dt_b_fed_asin_title) driving a small gear that engages with a geared turntable (ala Lego Technic Turntable).   
  * Gives us the ability to change the gear ratio to ensure we have the strength to turn/aim the gun assembly.  
* Commercial transit tripod base.   
  * Allows you to easily move it around plus can level it on uneven ground.  
  * [Amazon.com : transit tripod](https://www.amazon.com/s?k=transit+tripod)  
* [T Slot 2020 Aluminum Extrusion](https://www.amazon.com/dp/B0B7HQRQ5G?th=1) for frame  
  * Strong, relatively light, versatile, weather proof  
  * [M5 T Nut Screws Kit for 2020 Aluminum Extrusion](https://www.amazon.com/dp/B0DMCS8KW4?ref=ppx_yo2ov_dt_b_fed_asin_title&th=1)   
* Pan control: Use outer ring geared [Slewing bearing](https://en.wikipedia.org/wiki/Slewing_bearing) to support rotating parts  
  * [Amazon.com: ZCLGOOD 6 Inch Black Lazy Susan Turntable](https://www.amazon.com/dp/B0FPKTKY5C?ref=ppx_yo2ov_dt_b_fed_asin_title&th=1) with a 3D printed gear bolted to it  
  * [Amazon.com: STEPPERONLINE Nema 17 Stepper Motor](https://www.amazon.com/dp/B00PNEQKC0?ref=ppx_yo2ov_dt_b_fed_asin_title&th=1)   
  * [Amazon.com: STEPPERONLINE Mounting Plate and Bracket for Nema 17 Stepper Motor](https://www.amazon.com/dp/B09LCSBLF8?ref=ppx_yo2ov_dt_b_fed_asin_title)  
* Tilt control: To support rotating top rail for adjusting tilt  
  * Mount two [Pillow Block Bearings](https://www.amazon.com/Eowpower-Diameter-Mounted-Pillow-Bearing/dp/B07K68Z1RC) (e.g., KP08 or KFL08, \~$5–$10 each) onto the vertical [T-slot uprights](https://www.amazon.com/dp/B0B7HQRQ5G?th=1) on either side of the turret base.  
  * [Amazon.com: 8mm x 100mm 304 Stainless Steel Round Rod](https://www.amazon.com/dp/B0D5D3KFQX?ref=ppx_yo2ov_dt_b_fed_asin_title&th=1)   
  * Attach Shaft Collars or custom T-slot mounting plates to lock the tilting top rail directly onto that shaft.  
  * [Amazon.com: STEPPERONLINE Nema 17 Stepper Motor](https://www.amazon.com/dp/B00PNEQKC0?ref=ppx_yo2ov_dt_b_fed_asin_title&th=1)   
  * [Amazon.com: DC Stepper Motor 42 Single Row Straight Plate Mounting Bracket](https://www.amazon.com/dp/B0GCCC4F81?ref=ppx_yo2ov_dt_b_fed_asin_title)   
  * [Amazon.com: BLCCLOY 20Pcs 2020 Aluminum Extrusion Black Corner Bracket T Slot](https://www.amazon.com/dp/B08D6T9CGN?th=1)  
* How things stack up from top to bottom:  
  * Horizontal T-slot with 8mm steel rod at each end run through pillow bushing  
  * Vertical T-slot arms holding pillow bushings  
  * horizontal t-slot attached to turnable with regular t-slot fasteners  
  * 3D printed turntable gear  
    * recessed holes for bolts to go up and into t-slot above  
    * heat set inserts to attach to turntable bearing below  
  * Turntable bearing (lazy suzan) attached to t-slot base with regular t-slot fasteners  
  * Square t-slot base  
* How to mount and fire the gun?  
  * 3D print mount that screws directly into handle screws of paint ball gun and slips over top rail  
  * Mount has holes for Heschen HS-1564B solenoid with bolt through end to contact trigger  
  * [Heschen DC24V 1.5A DC Solenoid Electromagnet](https://www.amazon.com/dp/B09T2XVMQJ?ref=ppx_yo2ov_dt_b_fed_asin_title&th=1)  
* Power Supply  
  * [Amazon.com: PlusRoc 2-Pack Waterproof DC 12V/24V to 5V 5A Buck Converter, USB-C Output](https://www.amazon.com/dp/B0FD735LFG?ref=ppx_yo2ov_dt_b_fed_asin_title&th=1)  
  * [Amazon.com: Battery Terminal Connectors 1 Pair](https://www.amazon.com/dp/B0BV3628Q7?ref=ppx_yo2ov_dt_b_fed_asin_title)   
* How to weatherproof stepper motors? Electronics?  
  * 3D printed enclosure with ‘lid’ on the bottom so water won’t get in

## Trigger Circuit

To safely drive the [**Heschen HS-4564B 24V solenoid (1.5A)**](https://www.amazon.com/dp/B09T2XVMQJ?ref=ppx_yo2ov_dt_b_fed_asin_title&th=1) from the ESP32 (3.3V logic on GPIO16), we need a switching circuit (N-channel MOSFET) with proper flyback protection and gate drive resistors to isolate the 3.3V logic from the 24V inductive load.

[MOSFET Control Module, 30V 161A: Amazon.com: Industrial & Scientific](https://www.amazon.com/dp/B0CTMB6BQX?ref=ppx_yo2ov_dt_b_fed_asin_title) 

## Deterrant

## Paintball Gun

* [I Built an Xbox-Controlled Paintball Turret](https://www.youtube.com/watch?v=UVgqzoGp9NQ)   
* [Amazon.com : Action Village Kingman Spyder Victor Entry Paintball Gun Package Kit (Diamond Black) : Sports & Outdoors](https://www.amazon.com/Action-Village-Kingman-Paintball-Package/dp/B0BHXNYJYY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)   
* Usable range is 25-35 yards, max 50 yds

## 

  ## Non-Kinetic Options

Given that the civil/legal liability of firing actual paintballs in a suburban setting remains a significant barrier, replace the paintball gun with high-intensity directional payloads:

| Payload Type | Mechanism | Why It Works |
| :---- | :---- | :---- |
| **High-Pressure Water Solenoid** | 12V quick-response solenoid valve tied to a tight jet nozzle. | Delivers a hard physical shock/thump at 40–60 PSI without any legal liability. |
| **Ultrasonic / Directional Audio** | Targeted speaker playing wolf/hound barks or high-frequency distress calls. | Directional speakers restrict sound to the target area without waking neighbors. |
| **Strobe / Green Laser Pen** | Green laser module aimed lower than human eye-level. | Deer visual systems are exceptionally sensitive to green light wavelength contrast in pitch dark. |

## Airsoft Gun

* [Amazon.com : Game Face GF76 Electric Full/Semi-Auto Tactical Carbine Airsoft Rifle](https://www.amazon.com/dp/B00C87XZ5U?tag=riflepal-20&linkCode=ogi&th=1&psc=1#customerReviews)  
* [Automatic Electric Gun](https://airsoft2day.com/how-does-an-electric-airsoft-gun-work/) (AEG) are airsoft guns that are powered by an electric battery  
  * In summary, electric airsoft guns are powered by a battery that drives a motor, which compresses a spring and creates a burst of air that propels the BB out of the barrel. The firing mechanism is activated by a switch that sends an electrical current to the motor, while the loading mechanism uses a magazine to store and feed BBs into the gun.  
* Need a way to store enough ammunition protected from the elements and deliver it reliably to the firing chamber  
  * Airsoft typically have magazines that hold 150+ rounds (the ammo is much smaller as well)  
    * High capacity and drum magazines can hold significantly larger numbers of BBs  
  * I believe airsoft magazines and the smaller/harder ammo (6mm) will be less likely to bridge/fail to load but we should research this issue.  
* Need to be able to programmatically fire the gun  
  * We can take advantage of the AEG wiring and replace the trigger switch with a circuit driven by an embedded controller (Teensy, ESP32, etc) [to trigger the MOSFET and cause the gun to fire](https://schematron.org/airsoft-mosfet-wiring-diagram.html). This is fairly common practice in various electronic projects.  
* Airsoft guns are typically accurate to 50m with upgraded sniper rifles up to 100m  
  * More range is better as each turret can cover a greater area. It also means the sound they make to rotate the gun into position and fire is less likely to spook the deer.  
* Must be able to correctly calculate barrel position and angle  
  * The most simple/direct solution would be to use an [9DoF accelerometer/gyro/compass](https://www.adafruit.com/product/4517) attached to the gun directly that can be used to detect/compute the current orientation. Accuracy will depend entirely on the absolute accuracy of the 9 DoF IMU used.  
  * Could be accomplished by mounting the turret on a tripod with bubble levels and manually ensuring it is level. Then we use kinematics to compute Euler angles (roll, pitch and yaw) as we move the gun via motors/rotary encoders.  
    * May be able to use StallGuard feature of TMC2209 to calibrate and detect if/when stepper motors can’t turn and the position is unknown.  
    * May need to have rotary encoders to track gun movement (vs what was requested)  
    * Leveling of the turret can be automated with an MPU6050 and servo motors on each leg but this is complex and expensive (see the $500 [Benro Theta: the Intelligent Modular Travel Tripod | Benro](https://www.benro.com/en/product/benro-theta.html)).  
* Need to detect when the gun fails to shoot and shut down gracefully.

## Computer

* Raspberry Pie 5 8GB ($80)  
  * Need to determine how much compute is required and if this can support it.  
  * [Hailo-8L AI Kit 26 TOPS ($120)](https://www.seeedstudio.com/Raspberry-Pi-Al-HAT-26-TOPS-p-6243.html)  
* [NVIDIA Jetson Orin Nano](https://marketplace.nvidia.com/en-us/enterprise/robotics-edge/) ($500)?  
  * [plertvilai/birdCam\_jetson: BirdCam with Jetson Nano](https://github.com/plertvilai/birdCam_jetson)

## Vision

* Mount camera(s) on moving gun support so it tracks where the gun is aiming  
* Need a way to see the entire area within range, scan for and identify targets.  
  * Wide angle lens to see wide field of view and eliminate scanning  
  * Will need IR/thermal cameras so they work at dawn/dusk and in the dark.  
  * Will likely need IR illuminators to get desired range  
  * Need to be weatherproof  
    * [Wildlife Cam Case – naturebytes kit store](https://shop.naturebytes.org/products/wildlife-cam-case-by-naturebytes)  
  * May be able to use [security cameras](https://www.axis.com/products/axis-p4705-plve) as they have similar requirements  
* Cameras  
  * [Simplifying embedded vision for all. \- Arducam](https://www.arducam.com/)  
  * [Camera \- Raspberry Pi Documentation](https://www.raspberrypi.com/documentation/accessories/camera.html)  
* Need a way to compute the position of the selected target in 3D space.  
  * Depth camera? Lidar? Stereo Cameras?

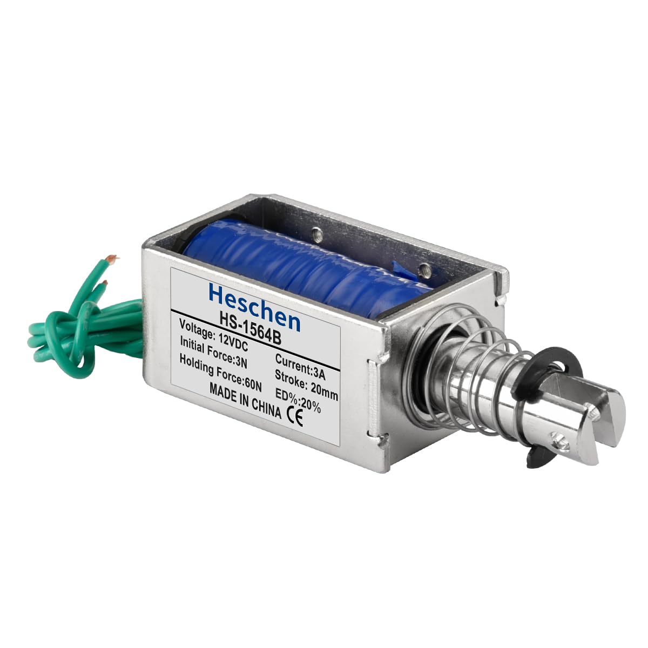
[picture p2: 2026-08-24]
docs/hardware specs/Heschen HS-1564B.jpg

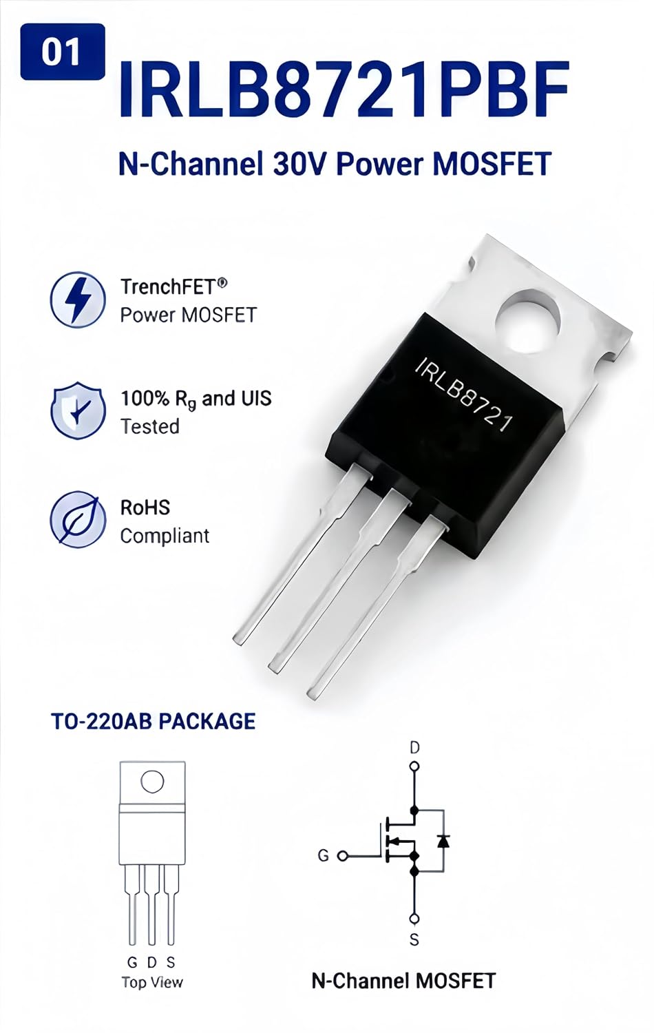
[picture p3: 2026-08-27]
docs/hardware specs/IRLB8721 30V Power MOSFET.jpg

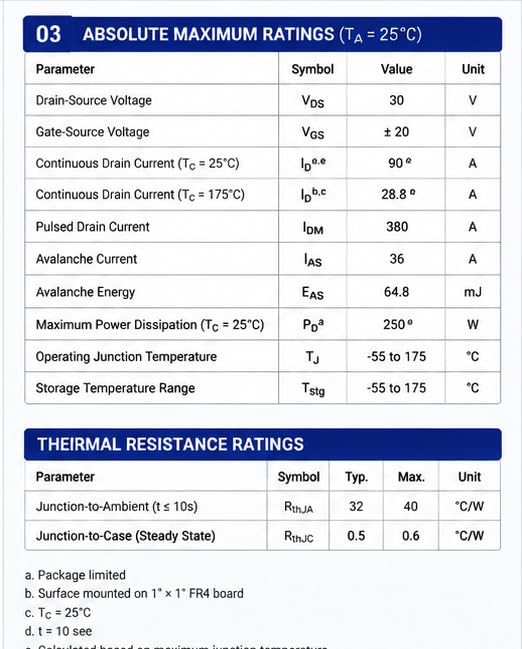
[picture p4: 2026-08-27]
docs/hardware specs/IRLB8721 30V Power MOSFET Specs.jpg

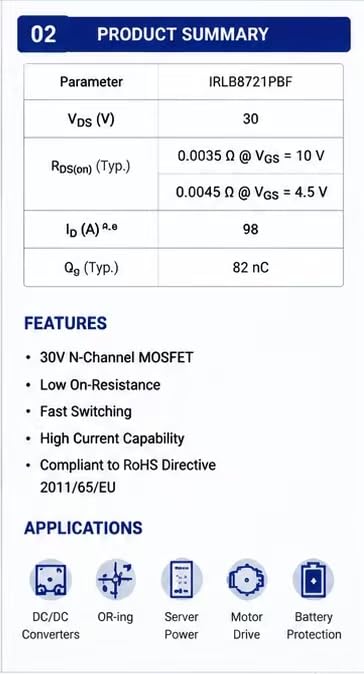
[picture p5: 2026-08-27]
docs/hardware specs/IRLB8721 30V Power MOSFET Product Summary.jpg

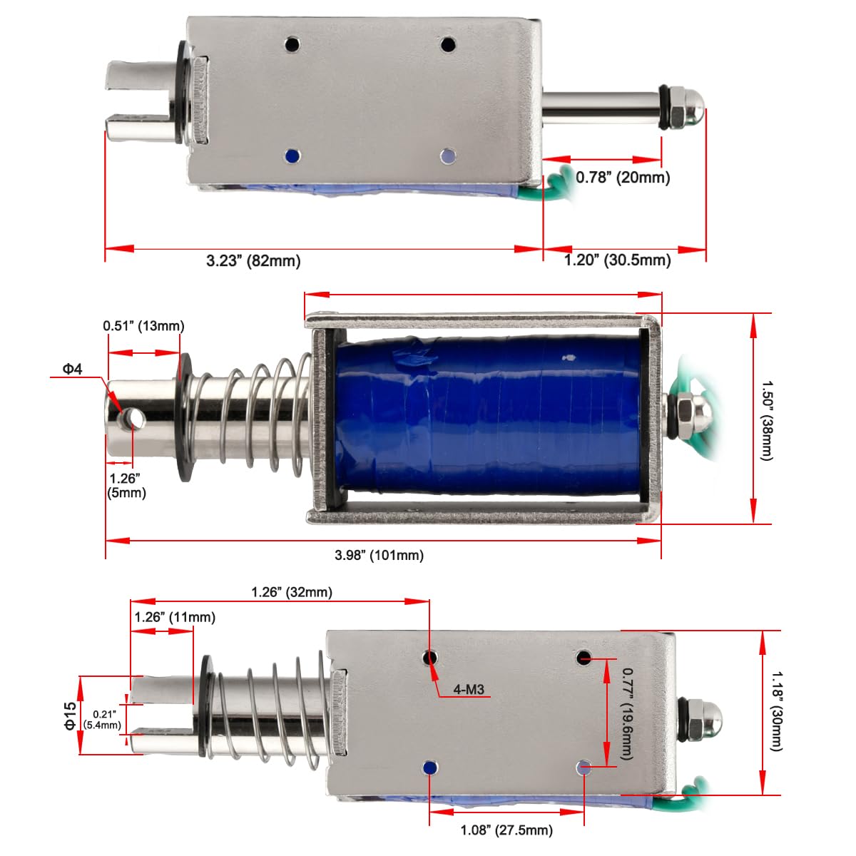
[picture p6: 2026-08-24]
docs/hardware specs/Heschen HS-1564B dimensions.jpg

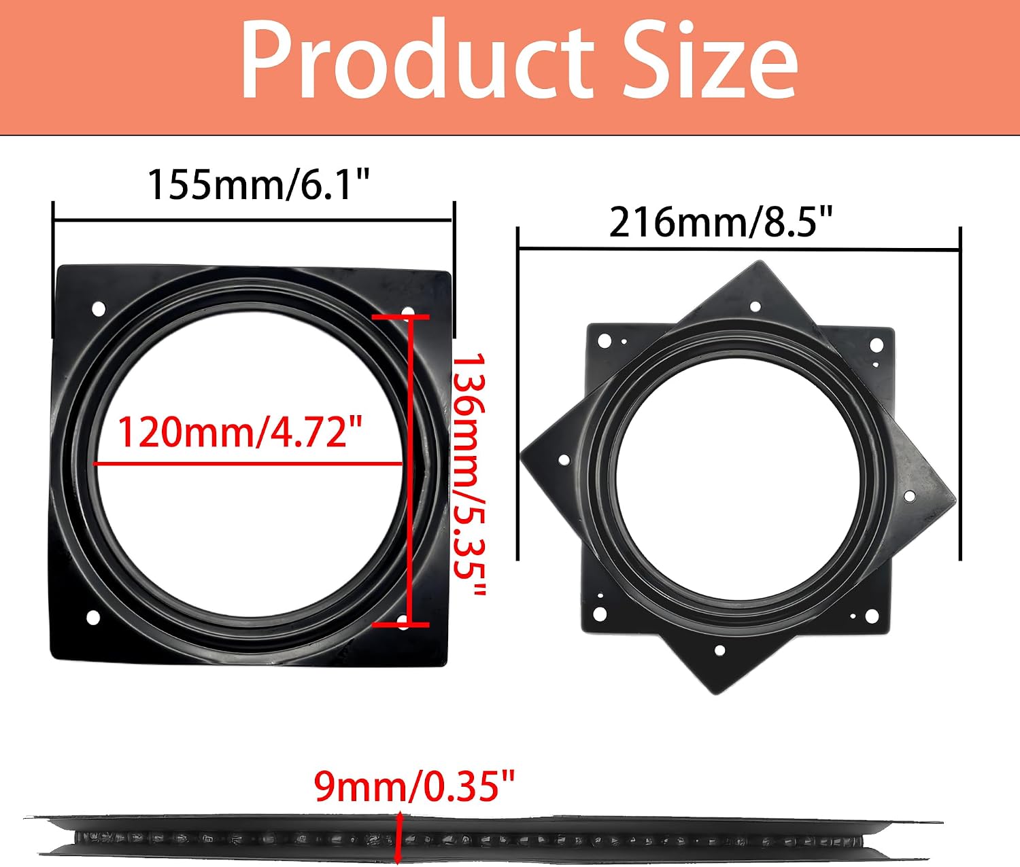
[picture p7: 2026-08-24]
docs/hardware specs/lazy susan specs.jpg

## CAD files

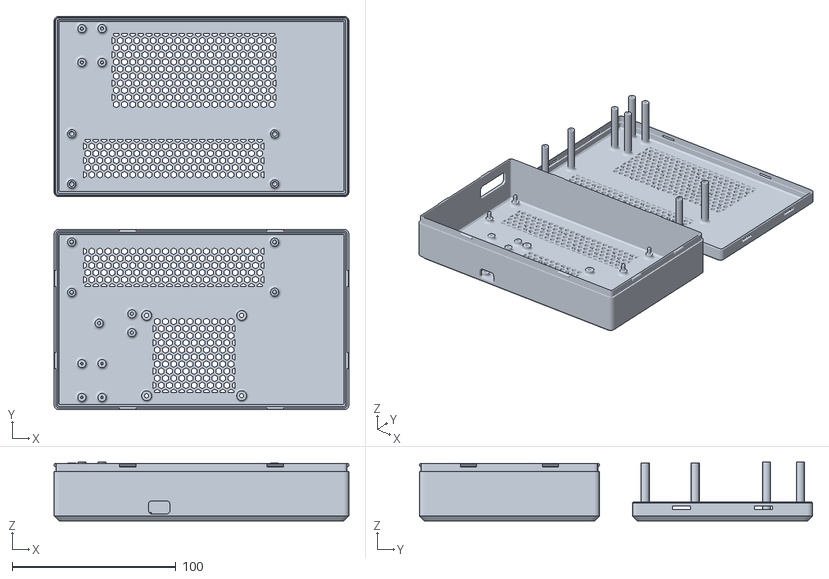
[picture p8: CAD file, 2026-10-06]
3d Print Models/projectbox.stl
180.0 x 240.0 x 35.8

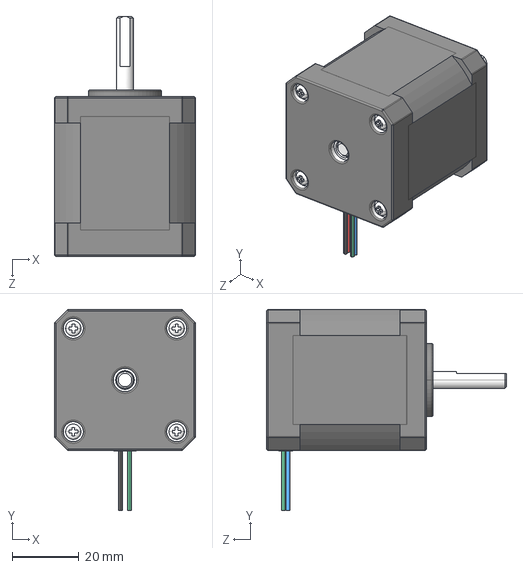
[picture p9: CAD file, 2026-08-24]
docs/hardware specs/17HS19-2004S1.STEP
42.3 x 60.3 x 72.0 mm

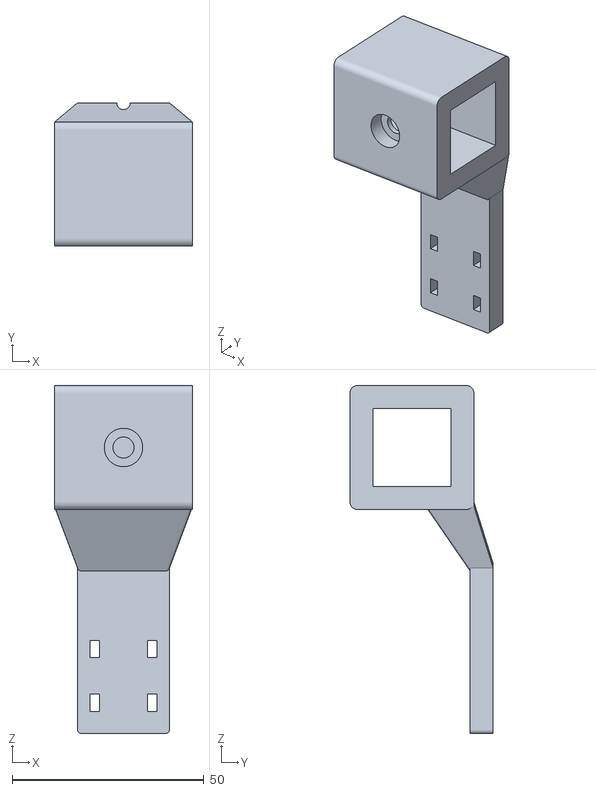
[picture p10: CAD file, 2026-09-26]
3d Print Models/camera_mount.stl
36.0 x 37.3 x 90.6

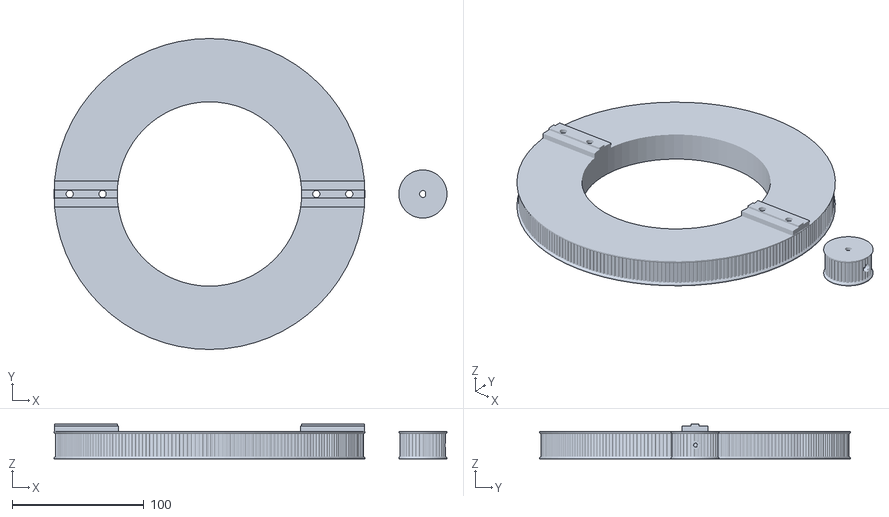
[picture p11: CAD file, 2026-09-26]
3d Print Models/pan_timing_gears.stl
298.5 x 236.2 x 26.5

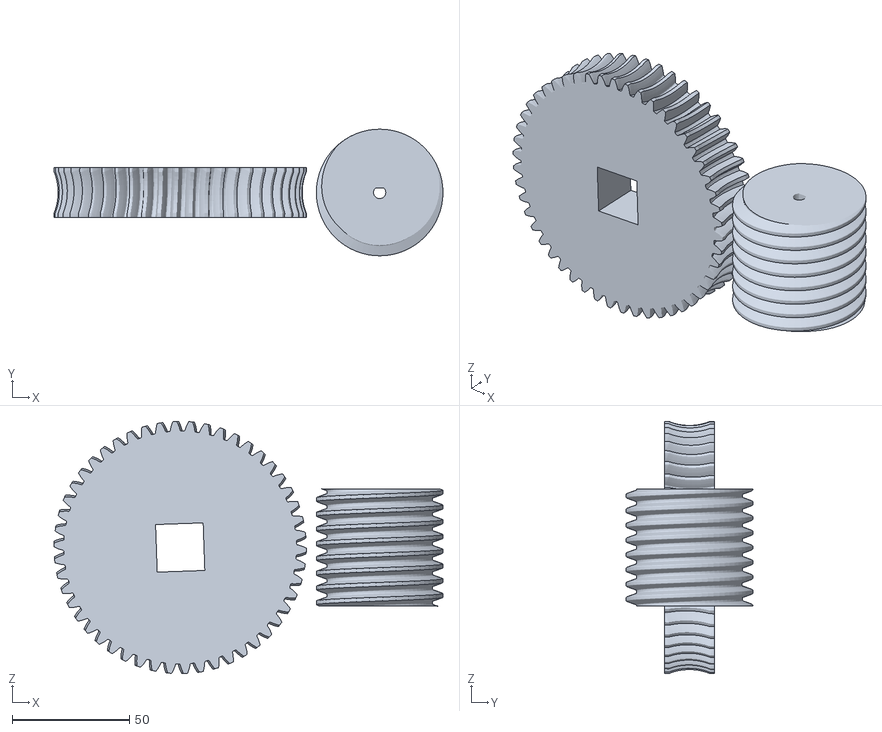
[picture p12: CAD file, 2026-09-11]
3d Print Models/tilt_gears.stl
165.8 x 54.0 x 107.6

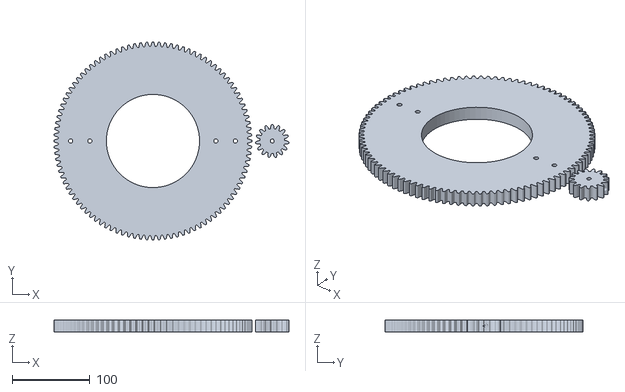
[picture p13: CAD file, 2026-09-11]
3d Print Models/pan_gears.stl
302.7 x 255.0 x 15.0

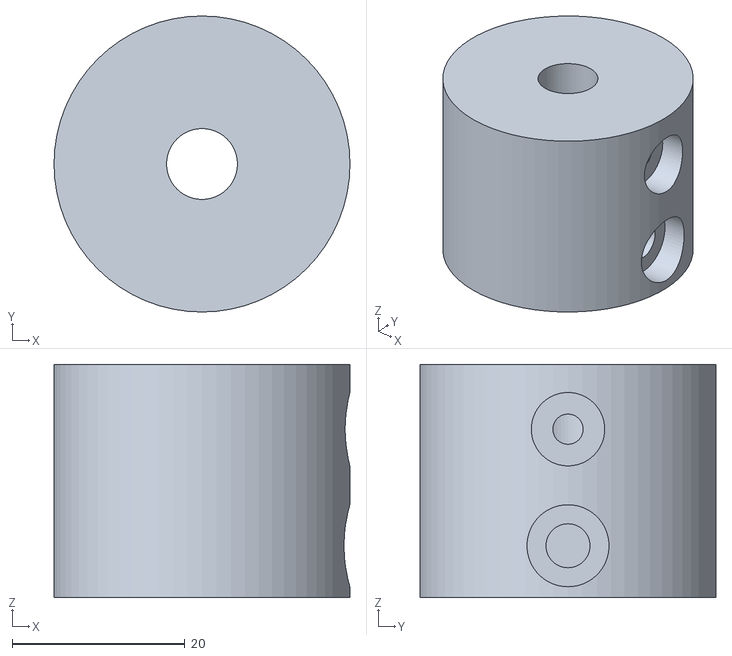
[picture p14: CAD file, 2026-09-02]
3d Print Models/2020 T-Slot Extrusion to 8mm Metal Rod End-Mount Adapter (Cylindrical).stl
34.3 x 34.3 x 27.0

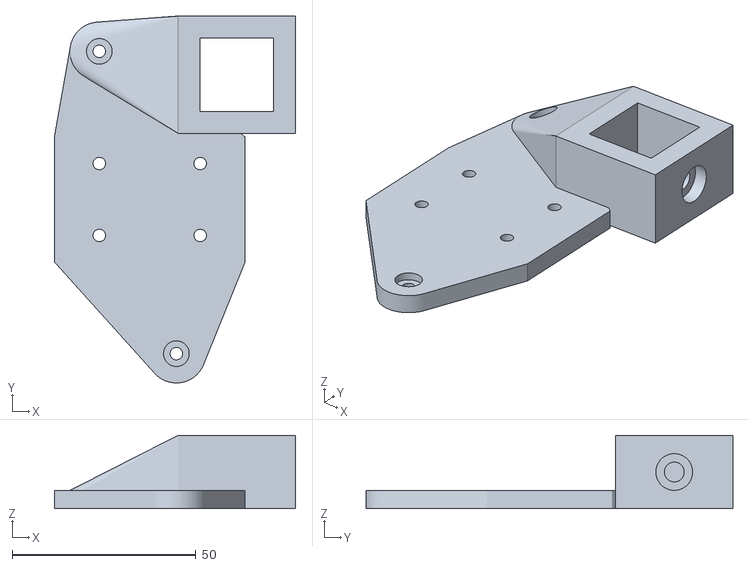
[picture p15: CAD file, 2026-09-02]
3d Print Models/spyder_victor_turret_mount.stl
65.8 x 100.0 x 20.0

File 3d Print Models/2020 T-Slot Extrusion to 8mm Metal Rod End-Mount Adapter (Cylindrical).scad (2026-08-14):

// ====================================================================
// 2020 T-Slot Extrusion to 8mm Metal Rod End-Mount Adapter (Cylindrical)
// ====================================================================
$fn = 64; // High resolution for smooth holes

// --- Parametric Dimensions ---
tslot_size             = 20.0; // Standard 2020 profile width (20mm)
tslot_clearance        = 0.0;  // Print tolerance for 2020 fit (+0.2mm)
socket_depth           = 12.0; // Depth of sleeve wrapping around 2020 end (20mm)

rod_diam               = 8.0;  // Metal rod diameter (8mm)
rod_clearance          = 0.1;  // Print tolerance for rod fit (+0.2mm)
rod_socket_depth       = 15.0; // Insertion depth for the 8mm rod (25mm)

wall_thickness         = 3.0;  // Wall thickness at thinnest point (3.5mm)
partition_thick        = 0.0;  // Divider thickness between 2020 end and rod (5.0mm)


// --- M4 Rod Set-Screw & Countersink Parameters ---
m4_rod_tap_diam        = 3.5;  // M4 tap hole diameter for threading into plastic (3.5mm)
m4_cs_diam             = 8.5;  // Recess diameter for M4 screw head (8.5mm)
m4_cs_depth            = 4.0;  // Countersink depth from outer cylinder surface (6.0mm)

// --- M5 - Clamps 2020 T-Slot & Countersink Parameters ---
m5_bolt_diam           = 5.1;  // Hole diameter for M5 bolt
m5_cs_diam             = 9.5;  // Recess diameter for M4 screw head (9.5mm)
m5_cs_depth            = 4.0;  // Countersink depth from outer cylinder surface (6.0mm)

// --- Derived Dimensions ---
tslot_width  = tslot_size + (tslot_clearance * 2);
outer_diam   = sqrt(2 * pow(tslot_width, 2)) + (wall_thickness * 2); 
total_length = socket_depth + partition_thick + rod_socket_depth;

// --- Main Part Generation ---
difference() {
    // 1. Solid Outer Cylinder Shell
    cylinder(d = outer_diam, h = total_length, center = true);

    // 2. 2020 Extrusion Socket (Bottom)
    translate([0, 0, -total_length/2 + socket_depth/2 - 0.1])
        cube([
            tslot_width, 
            tslot_width, 
            socket_depth + 0.2
        ], center = true);

    // 3. 8mm Rod Socket (Top)
    translate([0, 0, total_length/2 - rod_socket_depth/2 + 0.1])
        cylinder(
            d = rod_diam + (rod_clearance * 2), 
            h = rod_socket_depth + 0.2, 
            center = true
        );

    // 4. Center M5 Mounting Hole (Secures adapter into 2020 end-hole)
//    cylinder(d = m5_bolt_diam, h = total_length + 2, center = true);

    // 5. Top M4 Rod Set-Screw (Single-sided: Center to outer edge only)
    translate([0, 0, total_length/2 - (rod_socket_depth / 2)]) {
        rotate([0, 90, 0]) {
            // M4 Tap Hole extending from center axis out to outer wall only
            cylinder(d = m4_rod_tap_diam, h = outer_diam/2 + 1, center = false);

            // Entry-side Countersink/Counterbore for M4 screw head
            translate([0, 0, outer_diam/2 - m4_cs_depth])
                cylinder(d = m4_cs_diam, h = m4_cs_depth + 5);
        }
    }

    // 6. Bottom Side Clamping Set-Screw Hole (M5 - Clamps 2020 T-Slot)
    translate([0, 0, -total_length/2 + (socket_depth / 2)])
        rotate([0, 90, 0]) {
            // M5 Hole extending from center axis out to outer wall only
            cylinder(d = m5_bolt_diam, h = outer_diam/2 + 2, center = false);

            // Entry-side Countersink/Counterbore for M5 screw head
            translate([0, 0, outer_diam/2 - m5_cs_depth])
                cylinder(d = m5_cs_diam, h = m5_cs_depth + 5);
        }
}

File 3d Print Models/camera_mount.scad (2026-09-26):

include <BOSL2/std.scad>

$fn = 64;

// =========================================================================
// USER PARAMETERS & DIMENSIONS
// =========================================================================

// --- 2020 Extrusion Sleeve (Slide-On Block) ---
tslot_size         = 20.3; // 2020 extrusion width (+0.3mm clearance for 3D printing)
sleeve_wall        = 6.0;  // Solid perimeter wall thickness around extrusion
sleeve_len         = 36.0; // Length along the 2020 rail (X-axis)
sleeve_w           = tslot_size + (2 * sleeve_wall); // ~32.3mm (Y-axis)
sleeve_h           = tslot_size + (2 * sleeve_wall); // ~32.3mm (Z-axis)

// --- M5 Clamping Screw (Flat-Bottom Counterbore on -Y Rear Face) ---
m5_clamp_screw     = 5.5;  // M5 shank clearance diameter
m5_cbore_d         = 10.0; // Counterbore diameter for M5 socket head & tool
m5_cbore_depth     = 4.5;  // Counterbore shoulder pocket depth

// --- Camera Module 3 & Adapter Mount Hole Spacing (Facing +Y) ---
cam_hole_dx        = 21.0; // Horizontal spacing (X-axis)
cam_hole_dz        = 13.0; // Vertical spacing (Z-axis)

// --- M2 Heat-Set Inserts (Flush into Block Wall) ---
m2_insert_dia      = 2.7;  // Heat-set insert outer diameter
m2_insert_depth    = 4.0;  // Insert pocket depth
m2_overdepth       = 1.0;  // Clearance reservoir for displaced molten plastic

// --- Lower Arm: Shifted Drop Arm & Cable Channel ---
hdmi_clearance     = 68.0;
ext_w              = 24.0; // Width of the lower drop arm (mm along X)
y_shift            = 5.0;  // Shift arm forward by 5mm in +Y
cable_dia          = 3.5;  // Semi-circular channel for 3.3mm ultra-slim HDMI wire

// --- Zip-Tie Slot Dimensions ---
ziptie_thick       = 2.4;  // Thickness of slot in X (fits up to 2.2mm zip-tie)
ziptie_width       = 4.5;  // Height of slot in Z (fits up to 4.0mm zip-tie band)
ziptie_x_offset    = 7.5;  // Distance of left/right slots from center cable channel

// --- Vertical & Positional Calculations ---
cam_center_z       = 0.0;
front_y            = sleeve_w / 2;                           // Sleeve block front face (~16.15mm)
rear_y             = -sleeve_w / 2;                          // Sleeve block rear face (~ -16.15mm)
sleeve_wall_center = front_y - (sleeve_wall / 2);            // Center of original 6mm front sleeve wall
arm_front_y        = front_y + y_shift;                      // Shifted front face (~21.15mm)
arm_center_y       = sleeve_wall_center + y_shift;           // Shifted arm center in Y

lower_hole_z       = cam_center_z - (cam_hole_dz / 2); // Z = -6.5mm
ext_top_z          = -sleeve_h / 2;                    // Z = -16.15mm
ext_bottom_z       = lower_hole_z - hdmi_clearance;    // Z = -74.5mm
blend_h            = 14.0;                             // Height of transition curve
gusset_depth_y     = 6.0;                              // Rear anchor depth into sleeve base

// =========================================================================
// RENDER
// =========================================================================

camera_turret_mount();

// =========================================================================
// MODULE DEFINITION
// =========================================================================

module camera_turret_mount() {
    difference() {
        union() {
            // 1. Unified 2020 Rail Slide-On Block Housing
            cuboid([sleeve_len, sleeve_w, sleeve_h], rounding = 2, edges = "X");

            // 2. Continuous Arm & Gusset Transition
            hull() {
                // Top profile at base of sleeve: full front wall + underside gusset anchor
                translate([0, sleeve_wall_center - (gusset_depth_y / 2), ext_top_z + 1])
                    cuboid([sleeve_len, sleeve_wall + gusset_depth_y, 2], rounding = 1, edges = "Y");

                // Bottom profile at end of transition matching the shifted 24x6mm drop arm
                translate([0, arm_center_y, ext_top_z - blend_h - 1])
                    cuboid([ext_w, sleeve_wall, 2], rounding = 1, edges = "Y");
            }

            // 3. Main Lower Extension Arm (Shifted +5mm in Y, 6mm thickness preserved)
            translate([0, arm_center_y, (ext_top_z - blend_h + ext_bottom_z) / 2])
                cuboid([ext_w, sleeve_wall, (ext_top_z - blend_h) - ext_bottom_z], rounding = 1, edges = "Y");
        }

        // ================= SUBTRACTIONS =================

        // 1. Full 2020 Rail Bore through X-axis
        cube([sleeve_len + 10, tslot_size, tslot_size], center = true);

        // 2. M5 Rail Clamping Screw Hole (Rear Wall [-Y] into 2020 rear T-slot)
        // Passes completely from the outer rear face through into the inner extrusion slot
        translate([0, -(tslot_size / 2) + 2, 0])
            rotate([90, 0, 0]) {
                // Shank clearance hole extending cleanly into the inner cavity
                cyl(d = m5_clamp_screw, h = sleeve_wall + 4, anchor = BOTTOM);

                // Counterbore pocket positioned from the outer rear face
                translate([0, 0, sleeve_wall + 2 - m5_cbore_depth])
                    cyl(d = m5_cbore_d, h = m5_cbore_depth + 5, anchor = BOTTOM);
            }

        // 3. M2 Heat-Set Insert Pockets (4x, flush into front wall of sleeve)
        for (mx = [-cam_hole_dx / 2, cam_hole_dx / 2]) {
            for (mz = [-cam_hole_dz / 2, cam_hole_dz / 2]) {
                translate([mx, front_y, cam_center_z + mz])
                    rotate([-90, 0, 0])
                        cyl(d = m2_insert_dia, h = m2_insert_depth + m2_overdepth, anchor = TOP);
            }
        }

        // 4. Vertical HDMI Cable Channel (Shifted to the new +5mm front face)
        translate([0, arm_front_y, (lower_hole_z + ext_bottom_z) / 2])
            rotate([0, 0, 0])
                cyl(d = cable_dia, h = hdmi_clearance + 10, anchor = CENTER);

        // 5. Dual Zip-Tie Slots (Centered through the shifted 6mm wall)
        for (z_drop = [46, 60]) {
            for (x_side = [-ziptie_x_offset, ziptie_x_offset]) {
                translate([x_side, arm_center_y, lower_hole_z - z_drop])
                    cube([ziptie_thick, sleeve_wall + 4, ziptie_width], center = true);
            }
        }
    }
}

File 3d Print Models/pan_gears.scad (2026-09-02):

/* ========================================================================
   LAZY SUSAN RING GEAR (155mm TURNTABLE) & NEMA 17 PINION SET (BOSL2)
   ========================================================================
   - Lazy Susan: 155mm Square Plate (219.2mm diagonal)
   - Hole Spacing: 136mm x 136mm Square Pitch (Radius: 96.17mm)
   - Center Bore: 120.0mm Diameter
   - Gear Height: 10.0mm
   - Fully parametric counterbore & insert depths relative to gear_height
   ======================================================================== */

include <BOSL2/std.scad>
include <BOSL2/gears.scad>

$fn = 64; // Smooth curve resolution

/* --- VIEW / PRINT MODE --- */
// Options: "assembly" (view both in position), "ring" (print ring), "pinion" (print pinion)
mode = "assembly"; 

/* --- COMMON GEAR PARAMETERS --- */
module_val      = 2.5;   // Gear Module (2.5mm pitch)
pressure_angle  = 20;    // Standard 20-degree pressure angle
gear_height     = 15.0;  // Uniform gear thickness in Z (mm)

/* --- RING GEAR SPECIFICATIONS (155mm TURNTABLE) --- */
//ring_teeth      = 90;    // 90 Teeth -> Pitch Dia = 225.0mm, Root Dia = 218.75mm, Outer Dia = 230.0mm
ring_teeth      = 100;   // 100 Teeth -> Pitch Dia = 250.0mm, Root Dia = 218.75mm, Outer Dia = 255.0mm
inner_bore_dia  = 120.0; // Turntable center hole cutout (mm)

// 136mm square hole spacing: Radius = sqrt(68^2 + 68^2) = 96.167mm
ls_hole_pitch   = 136.0; 
mount_radius    = ls_hole_pitch / sqrt(2); // ~96.17mm

/* --- PINION GEAR SPECIFICATIONS (NEMA 17) --- */
pinion_teeth    = 15;    // 15 Teeth -> Pitch Dia = 37.5mm, Outer Dia = 42.5mm
//pinion_teeth    = 25;    // 25 Teeth -> Pitch Dia = 62.5mm, Outer Dia = 67.5mm
nema_shaft_dia  = 5.2;   // 5mm shaft clearance (+0.2mm for 3D printing)
nema_flat_dist  = 4.6;   // D-flat distance from rounded back (mm)

// Valley Center Alignment: 1/4 of the tooth pitch (360 / (4 * 15) = 6.0°)
pinion_valley_ang = 360.0 / (4 * pinion_teeth); // 6.0 degrees

/* --- FASTENER & COUNTERBORE SPECIFICATIONS --- */
// 1. Bottom Face M5 Heat-Set Inserts (Lazy Susan)
insert_hole_dia = 6.18;   // M5 heat-set insert pocket diameter (mm)
insert_depth    = min(6.0, gear_height - 2.0); // 6.0mm depth (leaves 4mm solid roof at 10mm height)

// 2. Top Face M5 2020 T-Slot Fasteners
m5_clearance_d  = 5.5;   // M5 2020 T-slot shank clearance hole (mm)
m5_head_cbore_d = 10.0;  // M5 head counterbore diameter (mm)
m5_shelf_thick  = 3.5;   // Solid plastic clamping shelf thickness left at top (mm)
m5_head_recess  = gear_height - m5_shelf_thick; // Calculated counterbore depth from bottom (~6.5mm)

// 3. Pinion M3 Set-Screw Fasteners
m3_screw_dia    = 3.2;   // M3 set-screw shank clearance hole (mm)
m3_cbore_dia    = 6.5;   // Flat-bottom counterbore diameter for M3 head (mm)
m3_head_height  = 3.5;   // Recess depth below tooth root valley (mm)

/* --- CALCULATED CENTER DISTANCE --- */
center_distance = (module_val * (ring_teeth + pinion_teeth)) / 2.0; // 131.25mm


/* ========================================================================
   MAIN DISPLAY SWITCH
   ======================================================================== */

if (mode == "assembly") {
    // Render Ring Gear at origin
    ring_gear();
    
    // Render NEMA 17 Pinion mesh aligned at exact pitch center distance
    translate([center_distance + 10, 0, 0])
        nema17_pinion();

} else if (mode == "ring") {
    ring_gear();

} else if (mode == "pinion") {
    nema17_pinion();
}


/* ========================================================================
   MODULE DEFINITIONS
   ======================================================================== */

// 1. LAZY SUSAN RING GEAR
module ring_gear() {
    difference() {
        // Base Gear Body
        spur_gear(
            mod = module_val,
            teeth = ring_teeth,
            thickness = gear_height,
            pressure_angle = pressure_angle,
            anchor = BOTTOM
        );

        // Full-Height 120mm Center Cutout
        translate([0, 0, -1])
            cyl(d = inner_bore_dia, h = gear_height + 2, anchor = BOTTOM);

        // Bottom Face: 4x M5 Heat-Set Inserts for 136mm x 136mm Lazy Susan
        for (angle = [45, 135, 225, 315]) {
            zrot(angle)
                translate([mount_radius, 0, -0.1])
                    cyl(d = insert_hole_dia, h = insert_depth + 0.1, anchor = BOTTOM);
        }

        // Top/Through: 45° Offset M5 Counterbored Holes for 2020 T-Slot
        for (angle = [0, 180]) {
            zrot(angle) {
                translate([mount_radius + 10, 0, 0]) {
                    // Full M5 Shank Clearance Through-Hole
                    translate([0, 0, -1])
                        cyl(d = m5_clearance_d, h = gear_height + 2, anchor = BOTTOM);
                    
                    // Parametric Flat Counterbore (leaves m5_shelf_thick solid material)
                    translate([0, 0, -0.1])
                        cyl(d = m5_head_cbore_d, h = m5_head_recess + 0.1, anchor = BOTTOM);
                }
            }
            zrot(angle) {
                translate([mount_radius - 15, 0, 0]) {
                    // Full M5 Shank Clearance Through-Hole
                    translate([0, 0, -1])
                        cyl(d = m5_clearance_d, h = gear_height + 2, anchor = BOTTOM);
                    
                    // Parametric Flat Counterbore (leaves m5_shelf_thick solid material)
                    translate([0, 0, -0.1])
                        cyl(d = m5_head_cbore_d, h = m5_head_recess + 0.1, anchor = BOTTOM);
                }
            }
        }
    }
}

// 2. NEMA 17 STEPPER PINION GEAR (VALLEY-ALIGNED & TRUE RADIAL RECESSED COUNTERBORE)
module nema17_pinion() {
    pinion_pitch_r = (module_val * pinion_teeth) / 2.0;               // 18.75mm
    pinion_root_r  = pinion_pitch_r - (1.25 * module_val);            // 15.625mm
    pinion_shelf_r = pinion_root_r - m3_head_height;                  // 12.125mm recessed shelf
    pinion_outer_r = (module_val * (pinion_teeth + 2)) / 2.0;         // 21.25mm
    flat_x_pos     = nema_flat_dist - (nema_shaft_dia / 2.0);         // 2.0mm

    difference() {
        // Main Pinion Body
        spur_gear(
            mod = module_val,
            teeth = pinion_teeth,
            thickness = gear_height,
            pressure_angle = pressure_angle,
            anchor = BOTTOM
        );

        // D-Shaft Bore (Aligned with valley angle)
        zrot(pinion_valley_ang)
            translate([0, 0, -1])
                d_shaft_bore(h = gear_height + 2);

        // M3 Recessed Counterbore Set-Screw Bore (Centered at mid-height Z = gear_height / 2)
        zrot(pinion_valley_ang) {
            translate([0, 0, gear_height / 2.0]) {
                // 1. M3 Shank Through-Hole (from D-flat out to recessed shelf)
                translate([flat_x_pos, 0, 0])
                    yrot(90)
                        cyl(d = m3_screw_dia, h = pinion_shelf_r - flat_x_pos, anchor = BOTTOM);

                // 2. Flat Counterbore Pocket (from recessed shelf out past tooth crests)
                translate([pinion_shelf_r, 0, 0])
                    yrot(90)
                        cyl(d = m3_cbore_dia, h = (pinion_outer_r - pinion_shelf_r) + 5, anchor = BOTTOM);
            }
        }
    }
}

// Helper: Standard NEMA 17 D-Shaft Cutout (Flat centered symmetrically on +X)
module d_shaft_bore(h) {
    flat_x = nema_flat_dist - (nema_shaft_dia / 2.0); // 2.0mm from center
    difference() {
        // Round shaft clearance
        cyl(d = nema_shaft_dia, h = h, anchor = BOTTOM);
        
        // Symmetrical D-flat cut on +X side
        translate([flat_x + (nema_shaft_dia / 2.0), 0, h / 2.0])
            cube([nema_shaft_dia, nema_shaft_dia * 2, h + 0.2], center = true);
    }
}

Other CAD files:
3d Print Models/pan_timing_gears.scad
3d Print Models/projectbox.scad
3d Print Models/spyder_victor_turret_mount.scad
3d Print Models/tilt_gears.scad

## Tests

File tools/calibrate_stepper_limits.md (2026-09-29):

# Bombardeer Bounded Kinematic Calibration Guide

This utility benchmarks the maximum stable acceleration and top speed for both the Pan and Tilt axes within their physical travel limits.

---

## 1. Hardware & Mechanical Setup

1. **Clear Turret Path:** Ensure all wiring harness slack, camera cables, and payload equipment can swing freely through the full travel envelope without binding.
2. **Center Turret:** Manually align the turret to mechanical center ($0^\circ$ pan, $0^\circ$ tilt) before powering up the ESP32.
3. **Power Up:** Connect the motor DC power supply and attach the ESP32 via USB.

---

## 2. Running the Benchmark

1. Open the project in your IDE (e.g., PlatformIO or Arduino IDE) and upload `calibrate_stepper_limits.cpp` to the ESP32.
2. Open the **Serial Monitor** set to **921600 baud**.
3. Follow the serial prompts:
   * Press **Enter** to begin the **PAN** axis calibration.
   * The motor will run an out-and-back sweep (`0 -> +MAX -> -MAX -> 0`) across the envelope.

---

## 3. Evaluating Each Test Pass

After each sweep, the console prompts:
`Did the axis move smoothly without missing steps? (y/n)`

* **Type `y` + Enter (Pass):** If the sweep was smooth with no stalling, grinding, or belt/gear skipping. The script will increment the parameter and run the next test.
* **Type `n` + Enter (Fail/Skip):** If the motor stalled, skipped steps, or audibly vibrated without moving. This halts Phase 1 or Phase 2 and locks in the last verified value.
* **Emergency Abort:** Press **Space** or **Enter** at any moment during a live move to trigger an immediate halt.

---

## 4. Test Phases per Axis

Each axis runs through two automated phases:

1. **Phase 1 (Max Acceleration):** The motor sweeps at a fixed cruise speed of $10,000\text{ steps/s}$ while increasing acceleration in $+5,000\text{ steps/s}^2$ increments to test pure inertial load.
2. **Phase 2 (Max Speed):** Using your confirmed acceleration, the speed increases in $+2,500\text{ steps/s}$ steps up to the calculated physical stroke limit.

Once Pan is complete, repeat the process for **TILT**.

---

## 5. Applying Values to Production (`main.cpp`)

At the conclusion of each test, the script outputs recommended production values using conservative engineering safety margins (80% of max acceleration, 85% of max speed):

```text
CALIBRATION SUMMARY: PAN AXIS
  RECOMMENDED PROD ACCEL (80%) : 20000 steps/s^2
  RECOMMENDED PROD SPEED (85%) : 25500 steps/s
```

Copy these values into your `main.cpp` configuration:

```cpp
#define PAN_STEPPER_ACCELERATION   <RECOMMENDED ACCEL PROD>
#define PAN_STEPPER_MAXSPEEDHZ     <RECOMMENDED PROD SPEED>

#define TILT_STEPPER_ACCELERATION  <RECOMMENDED ACCEL PROD>
#define TILT_STEPPER_MAXSPEEDHZ    <RECOMMENDED PROD SPEED>
```

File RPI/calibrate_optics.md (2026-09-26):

# Bombardeer Optical Focal Length Calibration Suite

`calibrate_optics.py` is an automated calibration utility designed to calculate the exact optical focal lengths (`fx` and `fy`) of the camera in pixels. It bridges the physical kinematics of the Bombardeer pan-tilt turret with camera pixel coordinates, ensuring that vision-based targeting and parallax compensation remain accurate.

---

## What It Does

The script executes controlled, bidirectional angular sweeps on the turret while tracking a stationary ArUco marker:

* **Large Angular Baselines:** Commands $320\text{ mrad}$ ($\sim 18.3^\circ$) on the pan axis and $140\text{ mrad}$ ($\sim 8.0^\circ$) on the tilt axis to generate large pixel shifts and minimize measurement error.

* **Mechanical Settling:** Monitors ESP32 telemetry status packets (`S ...`) for motion completion, then enforces a $2.5\text{ s}$ pause to let vibrations and gear resonance die down.

* **Statistical Filtering:** Captures $30$ frames at every stopping point, applying subpixel corner refinement and a $2\sigma$ outlier filter to reject jitter.

* **Backlash Compensation:** Sweeps both forward and backward across both axes, averaging the forward/reverse results and calculating gear backlash in pixels.

* **Pinhole Projection Solver:** Uses binary search to solve the non-linear angular displacement equation:

$$\left\vert{}\arctan\left(\frac{p_1 - c}{f}\right) - \arctan\left(\frac{p_2 - c}{f}\right)\right\vert{} = \theta_{\text{target}}$$

---

## Hardware & Environment Prerequisites

* **Turret Hardware:** Connected to the host via USB serial (`/dev/ttyUSB0`, `/dev/ttyACM0`, or `/dev/ttyUSB1`) running the ESP32 controller firmware at `115200` baud.

* **Camera:** Raspberry Pi Camera Module configured via `picamera2` (native $1280 \times 720$ mode).

* **Target Marker:** A printed **ArUco marker** from the `DICT_4X4_50` dictionary with **ID: 0**.

---

## Step-by-Step Instructions

### Step 1: Position the Turret and Target

1. Secure the turret on a rigid, stable surface to prevent base slipping during rapid motion.
2. Affix the ArUco marker (ID: `0`) to a stationary, vertical surface approximately $2\text{ to }5\text{ meters}$ away.

3. Ensure the marker is well lit and completely unobstructed.

### Step 2: Set Initial Marker Alignment

Because the script commands a positive pan sweep of $+320\text{ mrad}$, the camera rotates to the right, causing the marker in the video frame to move toward the right side of the screen.

* Manually align the turret so the marker starts on the **left side of the camera's field of view** ($X \approx 350\text{–}450\text{ px}$).

* Vertically, keep the marker slightly **above center** ($Y \approx 250\text{–}320\text{ px}$) to prevent it from sweeping off the bottom edge during the vertical displacement.

### Step 3: Run the Script

Execute the script from the Raspberry Pi terminal:

```bash
python3 calibrate_optics.py

```

The script will detect the serial port, initialize the camera, and wait for confirmation:

```text
[ALIGNMENT INSTRUCTIONS]
Place the ArUco marker toward the LEFT side of the screen (X ~= 350-450 px).
This allows the turret to execute a large 320 mrad sweep without losing it.

Press ENTER once the target is placed and camera has an unobstructed view...

```

Press **Enter** once the marker is confirmed in position.

### Step 4: Automated Calibration Sequence

The script runs the calibration cycle automatically without manual intervention:

1. **Position A (Baseline):** Samples 30 frames to establish the starting marker centroid.

2. **Pan Sweep (+320 mrad):** Moves to Position B, lets mechanical vibration settle, and computes forward `fx`.

3. **Pan Return (-320 mrad):** Moves back to Position A', calculates reverse `fx`, and outputs pan backlash.

4. **Tilt Sweep (+140 mrad):** Moves downward to Position C, settles, and computes forward `fy`.

5. **Tilt Return (-140 mrad):** Returns to baseline, computes reverse `fy`, and outputs tilt backlash.

### Step 5: Apply Calibrated Values

When the sweep completes, the script displays the averaged results:

```text
======================================================================
 OPTICAL CALIBRATION CONVERGED SUCCESSFULLY
======================================================================
Update bombardeer.py with these values:

FOCAL_LENGTH_X_PX = 985.50
FOCAL_LENGTH_Y_PX = 982.10
======================================================================

```

Copy the computed `FOCAL_LENGTH_X_PX` and `FOCAL_LENGTH_Y_PX` values into `bombardeer.py` and `turret_test.py`.

---

## Troubleshooting

* **`[ERROR] Could not connect to ESP32.`**
Ensure the ESP32 is connected via USB, permissions are granted (`sudo usermod -a -G dialout $USER`), and no background process (such as `bombardeer.py`) is occupying the serial port.

* **`[ERROR] Could not acquire target at start. Aborting.`**
Verify the marker is printed from `DICT_4X4_50` with `ID: 0` and that ambient lighting is sufficient.

* **`[ERROR] Lost marker! It may have swept off screen.`**
The marker was placed too close to the center or right edge at the start. Move the marker further left ($X \approx 350\text{ px}$) or reduce `TEST_PAN_MRAD` if working with a narrow field of view.

* **`[WARN] Jitter (...) px is high.`**
Ensure both the turret mount and the marker backing are rigidly stationary and not vibrating or flexing in the wind.

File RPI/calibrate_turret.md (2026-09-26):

# 🎯 Bombardeer Automated Optical-to-Mechanical Calibration Suite

`calibrate_turret.py` is an automated calibration script that computes the precise conversion ratios between **camera pixel displacements** and **stepper motor steps** for both the Pan and Tilt axes.

By sweeping the turret across a known step grid while continuously tracking a stationary target, the script uses linear regression to calculate:

* `STEPS_PER_PIXEL_PAN`

* `STEPS_PER_PIXEL_TILT`

* Coordinate inversion flags (`PAN_INVERT`, `TILT_INVERT`)

The results are automatically saved as JSON to `calibration_data.json` for ingestion by downstream targeting software.

---

## ⚙️ How It Works

1. **Hardware Link & Zeroing:** Connects to the ESP32 via serial (`115200` baud) and zeroes the mechanical coordinates using the `H` command.

2. **Camera & Perception:** Captures $1280 \times 720$ video using native `Picamera2` (with horizontal and vertical sensor flip applied). It enhances grayscale frames with CLAHE (Contrast Limited Adaptive Histogram Equalization) and locates a standard ArUco marker (`DICT_4X4_50`).

3. **Motion Grid Sweep:**
* **Pan Axis:** Sweeps through `[-1200, -600, 0, 600, 1200]` steps.

* **Tilt Axis:** Sweeps through `[-1000, -500, 0, 500, 1000]` steps.

4. **Vibration Dampening & Motion Queries:** Uses `Q` commands to poll the ESP32 until the motors report completion (`R ... 0`), adding a $150\text{ ms}$ mechanical settling delay before reading pixel positions.

5. **Multi-Frame Median Centroiding:** Captures 5 frames at each waypoint and calculates the median $X$ and $Y$ coordinates to eliminate optical noise and micro-jitter.

6. **Regression Analysis:** Computes a first-degree polynomial fit (`numpy.polyfit`) correlating motor step counts to pixel coordinates.

---

## 🧰 Prerequisites

* **Hardware:**
* Bombardeer Turret connected to the Raspberry Pi via USB serial (`/dev/ttyUSB0` or `/dev/ttyACM0`).

* Raspberry Pi Camera Module aligned with the turret.

* One printed **ArUco marker** from the `DICT_4X4_50` dictionary.

* **System Packages & Python Dependencies:**
```bash
sudo apt install -y python3-opencv python3-serial python3-numpy python3-picamera2

```

---

## 📋 Step-by-Step Instructions

### Step 1: Physical Setup

1. Mount or place the turret on a stable, vibration-free surface with complete clearance to rotate.

2. Place the printed ArUco marker directly in front of the camera, approximately **$1.5\text{ to }3\text{ meters}$** away.

3. Ensure the marker is roughly centered in the camera's line of sight and well-illuminated without glare.

### Step 2: Stop Conflicting Processes

Ensure no other services or scripts (such as `bombardeer.py`) are using the camera or serial port:

```bash
pkill -f bombardeer.py

```

### Step 3: Run the Calibration Script

Execute the script with Python 3:

```bash
python3 calibrate_turret.py

```

1. The script will initialize the camera, locate the serial port, and print the confirmation prompt:

```text
=======================================================
    BOMBARDEER AUTOMATED CALIBRATION SYSTEM
=======================================================
1. Place an ArUco marker directly in view of the turret.
2. Ensure the turret has mechanical clearance to move.

Press ENTER when the marker is placed and visible...

```

2. Confirm the marker is visible and unobstructed, then press **Enter**.

### Step 4: Automated Execution

* **Target Check:** Verifies marker detection across 8 sample frames and records the initial optical center position.

* **Origin Setting:** Sends `H` to reset the starting point to $(0, 0)$.

* **Pan Sweeps:** Moves the Pan axis through 5 positions while keeping Tilt at $0$, recording the pixel $X$ position at each stop.

* **Tilt Sweeps:** Returns Pan to $0$ and sweeps the Tilt axis through 5 vertical positions, recording the pixel $Y$ position.

* **Home Return:** Returns both axes to $(0, 0)$.

### Step 5: Verify the Output

Upon completion, the final steps-per-pixel ratios are displayed:

```text
=======================================================
              CALIBRATION COMPLETE                     
=======================================================
 Pan Axis Ratio  : 3.421 steps / pixel
 Tilt Axis Ratio : 25.814 steps / pixel
=======================================================
[Success] Configuration saved to /home/ben/Bombardeer/calibration_data.json

```

The output file (`/home/ben/Bombardeer/calibration_data.json`) is populated with the calibration results:

```json
{
    "timestamp": 1727375519.123,
    "STEPS_PER_PIXEL_PAN": 3.421,
    "STEPS_PER_PIXEL_TILT": 25.814,
    "PAN_INVERT": false,
    "TILT_INVERT": false
}

```

---

## 🔍 Troubleshooting

* **`[Error] Could not locate ESP32 serial port. Exiting.`**
* Verify the USB cable is plugged in and recognized using `ls /dev/ttyUSB* /dev/ttyACM*`.

* Ensure your user has dialout privileges: `sudo usermod -a -G dialout $USER`.

* **`[ERROR] No ArUco marker detected! Check alignment and lighting.`**
* Confirm the marker belongs to `DICT_4X4_50`.

* Improve ambient lighting or move the marker closer to the camera.

* **`[Warning] Marker lost at pan/tilt step X. Skipping point.`**
* The calibration step offsets (`PAN_OFFSETS` or `TILT_OFFSETS`) moved the camera so far that the marker went out of the frame.

* Move the marker farther away from the turret to widen the effective field of view, or reduce the offset values in `PAN_OFFSETS` / `TILT_OFFSETS` at the top of `calibrate_turret.py`.

* **`[ERROR] Insufficient data points collected to perform calibration.`**
* The script requires at least 3 valid marker readings per axis to perform regression. Ensure the marker stays inside the frame during the sweeps.

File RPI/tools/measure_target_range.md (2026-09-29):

# Target Measurement & Range Calibration Tool

`measure_target_range.py` is a standalone single-shot diagnostic utility that initializes the Raspberry Pi Camera Module, captures a single frame, detects a standard ArUco marker, measures its pixel dimensions, and validates distance estimation geometry.

---

## 🎯 What It Does

1. **Native Sensor Capture**: Configures `Picamera2` to capture a $1280 \times 720$ frame using on-sensor binning (`output_size: (2304, 1296)`)[cite: 4].
2. **Subpixel Geometry Extraction**: Locates the `DICT_4X4_50` marker (ID: 0) and computes the average pixel edge length across all four edges to minimize perspective distortion error[cite: 4].
3. **Pinhole Distance Estimation**: Evaluates the real-time distance estimate in both meters and feet:
   $$D = \frac{W_{\text{real}} \times f_{\text{px}}}{W_{\text{px}} \times 1000}$$
4. **Intrinsics Solving (Optional)**: If you provide a ground-truth physical tape-measured distance (`--distance`), the script solves for the exact optical focal length ($f_{\text{px}}$) and the milliradians-per-pixel ratio ($1000 / f_{\text{px}}$).

---

## 📋 Prerequisites

Ensure your system has the standard Bombardeer computer vision dependencies installed:

```bash
sudo apt update
sudo apt install -y python3-opencv python3-numpy python3-picamera2

```

Ensure no conflicting processes (like `bombardeer.py`) are actively using the camera:

```bash
pkill -f bombardeer.py

```

---

## 🚀 How to Use

### 1. Simple Distance Verification

Hold the $100\text{ mm}$ ($10\text{ cm}$) ArUco target at any test distance (e.g. 6 feet) facing the camera:

```bash
python3 measure_target_range.py

```

**Example Output:**

```text
[1/3] Initializing Camera Module via Picamera2...
[2/3] Capturing diagnostic frame...
[3/3] Processing ArUco geometry (DICT_4X4_50)...

============================================================
           TARGET MEASUREMENT RESULTS
============================================================
 Target Marker ID       : 0
 Measured Target Width  : 29.02 pixels
 Individual Edges       : T=29.1px, R=29.0px, B=29.0px, L=28.9px
------------------------------------------------------------
 Using Focal Length     : 540.4 px
 Target Physical Width  : 100.0 mm
 Estimated Distance     : 1.862 meters (6.11 feet)
============================================================

```

---

### 2. Calibrate & Solve New Lens Intrinsics

To calculate the exact focal length for a new lens or crop mode, place the $100\text{ mm}$ marker at an exact measured tape distance (e.g., $2.000\text{ meters}$) and supply the `--distance` argument:

```bash
python3 measure_target_range.py --distance 2.0

```

**Example Output:**

```text
============================================================
           TARGET MEASUREMENT RESULTS
============================================================
 Target Marker ID       : 0
 Measured Target Width  : 27.02 pixels
 Individual Edges       : T=27.0px, R=27.1px, B=27.0px, L=27.0px
------------------------------------------------------------
 Using Focal Length     : 540.4 px
 Target Physical Width  : 100.0 mm
 Estimated Distance     : 2.000 meters (6.56 feet)
------------------------------------------------------------
          CALIBRATED INTRINSICS (SOLVED)
------------------------------------------------------------
 Ground Truth Distance  : 2.000 meters (6.56 feet)
 Solved FOCAL_LENGTH_PX : 540.40
 Solved MRAD_PER_PIXEL  : 1.8505 mrad/px
============================================================

```

---

## 🔧 Updating `bombardeer.py` with Solved Values

Once `measure_target_range.py --distance <METERS>` outputs the **`CALIBRATED INTRINSICS (SOLVED)`** block, transfer those values into `bombardeer.py` to keep targeting calculations, parallax convergence, and HUD telemetry aligned.

1. Open `bombardeer.py` in your text editor:
```bash
nano /home/ben/Bombardeer/bombardeer.py

```

2. Locate the **`Configuration & Hardware Calibration`** section near line 65:

```python
# Camera Optical Intrinsics (RPi Cam Module 3 Wide NoIR @ 1280x720 native crop)
FOCAL_LENGTH_PX = 540.4
MRAD_PER_PIXEL_X = 1000.0 / FOCAL_LENGTH_PX  # ~1.8505 mrad/px
MRAD_PER_PIXEL_Y = 1000.0 / FOCAL_LENGTH_PX  # ~1.8505 mrad/px
```[cite: 4]

```

3. Update `FOCAL_LENGTH_PX` with the `Solved FOCAL_LENGTH_PX` value printed by the calibration tool:
```python
# Replace with the exact solved focal length from measure_target_range.py
FOCAL_LENGTH_PX = 540.40
MRAD_PER_PIXEL_X = 1000.0 / FOCAL_LENGTH_PX  # Automatically recalculates mrad/px
MRAD_PER_PIXEL_Y = 1000.0 / FOCAL_LENGTH_PX
```[cite: 4]

```

4. Save and exit (`Ctrl+O`, `Enter`, `Ctrl+X` in nano).
5. Restart the Bombardeer service or script:
```bash
python3 /home/ben/Bombardeer/bombardeer.py

```

---

## ⚙️ Command-Line Arguments

| Flag | Type | Default | Description |
| --- | --- | --- | --- |
| `--distance` | `float` | `None` | Ground-truth distance from camera lens to target in **meters**. Triggers focal length solving. |
| `--width` | `float` | `100.0` | Physical outer black edge width of the marker in **millimeters**.

 |
| `--focal-length` | `float` | `540.4` | Assumed optical focal length in pixels (540.4 for IMX708 Wide NoIR).

 |

---

## 🔍 Troubleshooting

* **`[FAIL] No ArUco marker detected!`**:
Ensure the marker belongs to the `DICT_4X4_50` dictionary and has sufficient lighting without reflections or glare on glossy paper.

* **Camera Resource Busy**:
If the script reports that the camera device is busy, run `pkill -f python3` to terminate any hanging background instances of `bombardeer.py`.

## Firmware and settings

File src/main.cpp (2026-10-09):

/*
    Bombardeer Autonomous Wildlife Deterrent Turret Controller
    ----------------------------------------------------------
    - Native Milliradian (mrad) Motion Protocol:
        * P <pan_mrad> <tilt_mrad> : Atomic absolute waypoint target (mrad)
        * V <pan_s> <tilt_s>       : Dynamic continuous velocity trim (mrad/s)
        * X                        : Immediate dynamic controlled halt
        * H                        : Zero current mechanical coordinates
        * T <0|1>                  : Autonomous solenoid trigger enable/disable
        * S <p> <t> <f> <m>        : 20 Hz deterministic telemetry stream
    - FastAccelStepper hardware-timed trapezoidal acceleration profiles.
    - TMC2209 silent stepping with dynamic torque transition.
    - Automated solenoid trigger pulse state machine.
    - Xbox Series X Bluetooth controller manual override with auto-timeout.
    - Non-blocking zero-allocation serial streaming parser with framing watchdog.
    - Failsafe serial timeout watchdog against host disconnect or reboot.
*/

#include <Arduino.h>
#include <TMCStepper.h>
#include <FastAccelStepper.h>
#include <XboxSeriesXControllerESP32_asukiaaa.hpp>
#include <errno.h>
#include "debug.h"

// ============================================================================
// ESP32 Pin Assignments
// ============================================================================

// Driver 1: Pan Axis
#define PAN_USTEP_PIN1 04
#define PAN_USTEP_PIN2 27
#define PAN_STEP_PIN 26
#define PAN_DIR_PIN 25

// Driver 2: Tilt Axis
#define TILT_USTEP_PIN1 18
#define TILT_USTEP_PIN2 05
#define TILT_STEP_PIN 33
#define TILT_DIR_PIN 32

#define SHARED_ENABLE_PIN 19

// TMC2209 Single-Wire UART Pins (Shared UART2)
#define TMC_RX_PIN 16 // ESP32 RX2 connected to TMC2209 TX/RX pins
#define TMC_TX_PIN 17 // ESP32 TX2 connected through 1k ohm resistor
#define SERIAL_PORT Serial2
#define R_SENSE 0.11f // Standard sense resistor value for stepsticks

// Driver Addresses on the shared UART bus
#define PAN_DRIVER_ADDR 0b00  // MS1=GND, MS2=GND
#define TILT_DRIVER_ADDR 0b01 // MS1=VCC, MS2=GND

// Actuators
#define PIN_SOLENOID 13

// ============================================================================
// Milliradian Kinematic Conversion Constants
// ============================================================================
// Standard 1.8 deg NEMA 17 motor: 200 full steps/rev * 16 usteps = 3200 steps/rev
#define STEPPER_FULL_STEPS 200.0
#define STEPPER_MICROSTEPS 16.0
#define STEPS_PER_MOTOR_REV (STEPPER_FULL_STEPS * STEPPER_MICROSTEPS) // 3200.0 steps/rev

// Pan Axis: copied from pan_timing_gears.scad
#define PAN_RING_TEETH 246.0  // ring_teeth
#define PAN_PINION_TEETH 37.0 // pinion_teeth

// Tilt Axis: copied from tilt_gears.scad
#define TILT_GEAR_TEETH 50.0 // teeth
#define TILT_WORM_STARTS 1.0 // starts

// Mathematical constants
#define K_PI 3.14159265358979323846
#define MRAD_PER_REV (2000.0 * K_PI) // ~6283.1853 mrad

// Compile-time ratio calculations
constexpr double PAN_GEAR_RATIO = PAN_RING_TEETH / PAN_PINION_TEETH;
constexpr double PAN_STEPS_PER_REV = STEPS_PER_MOTOR_REV * PAN_GEAR_RATIO;
constexpr double PAN_STEPS_PER_MRAD = PAN_STEPS_PER_REV / MRAD_PER_REV;
constexpr double PAN_MRAD_PER_STEP = MRAD_PER_REV / PAN_STEPS_PER_REV;

constexpr double TILT_GEAR_RATIO = TILT_GEAR_TEETH / TILT_WORM_STARTS;
constexpr double TILT_STEPS_PER_REV = STEPS_PER_MOTOR_REV * TILT_GEAR_RATIO;
constexpr double TILT_STEPS_PER_MRAD = TILT_STEPS_PER_REV / MRAD_PER_REV;
constexpr double TILT_MRAD_PER_STEP = MRAD_PER_REV / TILT_STEPS_PER_REV;

inline long panMradToSteps(long mrad)
{
    return (mrad >= 0) ? (long)((mrad * PAN_STEPS_PER_MRAD) + 0.5)
                       : (long)((mrad * PAN_STEPS_PER_MRAD) - 0.5);
}

inline long panStepsToMrad(long steps)
{
    return (steps >= 0) ? (long)((steps * PAN_MRAD_PER_STEP) + 0.5)
                        : (long)((steps * PAN_MRAD_PER_STEP) - 0.5);
}

inline long tiltMradToSteps(long mrad)
{
    return (mrad >= 0) ? (long)((mrad * TILT_STEPS_PER_MRAD) + 0.5)
                       : (long)((mrad * TILT_STEPS_PER_MRAD) - 0.5);
}

inline long tiltStepsToMrad(long steps)
{
    return (steps >= 0) ? (long)((steps * TILT_MRAD_PER_STEP) + 0.5)
                        : (long)((steps * TILT_MRAD_PER_STEP) - 0.5);
}

// ============================================================================
// Physical Travel Boundaries (FastAccelStepper Steps)
// ============================================================================
// Pan: +-180.0 deg (+-0.5 revs = 360 deg total continuous sweep)
#define PAN_MAX_DEGREES 180.0
constexpr long PAN_MAX_STEPS = (long)((PAN_STEPS_PER_REV * (PAN_MAX_DEGREES / 360.0)) + 0.5);
constexpr long PAN_MIN_STEPS = -PAN_MAX_STEPS;

// Tilt: +-22.5 deg (+-1/16 revs = 45 deg total vertical envelope)
#define TILT_MAX_DEGREES 22.5
constexpr long TILT_MAX_STEPS = (long)((TILT_STEPS_PER_REV * (TILT_MAX_DEGREES / 360.0)) + 0.5);
constexpr long TILT_MIN_STEPS = -TILT_MAX_STEPS;

/*
    Timing for Heschen HS-1564B / HS-4564B Solenoid
    * SOLENOID_PULSE_LENGTH = 40-60 ms
    * SOLENOID_COOLDOWN_LENGTH = 190 ms
    * Total cycle = 250 ms (4.0 BPS)
*/
constexpr uint32_t SOLENOID_PULSE_LENGTH = 60;
constexpr uint32_t SOLENOID_COOLDOWN_LENGTH = 190;
constexpr uint32_t MAX_AUTONOMOUS_FIRE_DURATION_MS = 2000;

// Host Serial Link Watchdog Timeout (500ms without serial data -> halt autonomous motion)
constexpr uint32_t SERIAL_WATCHDOG_TIMEOUT_MS = 500;

// Xbox Controller Deadzone and Trigger Thresholds
constexpr float DEADZONE_RADIUS = 0.30f;
constexpr float TRIGGER_THRESHOLD = 0.15f;
constexpr unsigned long MANUAL_OVERRIDE_TIMEOUT_MS = 400;

// Bind to any Xbox controller
XboxSeriesXControllerESP32_asukiaaa::Core xboxController;

// ============================================================================
// Stepper Library Configuration & Instantiations
// ============================================================================

#define PAN_STEPPER_ACCELERATION 13500 // Benchmarked production acceleration (75% limit)
#define PAN_STEPPER_MAXSPEEDHZ 11600   // Benchmarked production max speed (80% limit)
#define PAN_STEPPER_MINSPEEDHZ 15

#define TILT_STEPPER_ACCELERATION 50000 // Benchmarked production acceleration (~72% limit)
#define TILT_STEPPER_MAXSPEEDHZ 14800   // Benchmarked production max speed (80% limit)
#define TILT_STEPPER_MINSPEEDHZ 15

#define STEPPER_HYSTERESISHZ 300
#define STEPPER_EXPONENT 2.0f // 1.0f = linear, 2.0f = quadratic, 3.0f = cubic

// TMCStepper Driver Configuration Objects
TMC2209Stepper panTMC(&SERIAL_PORT, R_SENSE, PAN_DRIVER_ADDR);
TMC2209Stepper tiltTMC(&SERIAL_PORT, R_SENSE, TILT_DRIVER_ADDR);

// FastAccelStepper Engine & Motor Handles
FastAccelStepperEngine engine = FastAccelStepperEngine();
FastAccelStepper *panStepper = NULL;
FastAccelStepper *tiltStepper = NULL;

static bool autoFireRequested = false;
static uint32_t autoFireStartTime = 0;
static bool manualOverrideActive = false;
static unsigned long lastSerialRxTime = 0;

// Control Modes
enum MotionMode
{
    MODE_VELOCITY,
    MODE_POSITION
};
static MotionMode currentMotionMode = MODE_VELOCITY;

// Autonomous Target Speeds (mrad/s)
static long commandedPanSpeed = 0;
static long commandedTiltSpeed = 0;

// Active Applied Stepper States
static long appliedPanSpeed = 0;
static long appliedTiltSpeed = 0;
static int activePanDir = 0; // -1 = backward, 0 = stopped, 1 = forward
static int activeTiltDir = 0;

// ============================================================================
// TMC2209 Driver Configuration
// ============================================================================

/*
 * Configure TMC2209 Driver Parameters deterministically over UART with read-back validation
 */
bool initTMC2209(TMC2209Stepper &driver, const char *axisName, uint16_t current_mA, float hold_multiplier = 0.25f, bool forceSpreadCycle = false)
{
    driver.begin();

    // 1. Verify basic UART Communication
    uint8_t result = driver.test_connection();
    if (result != 0)
    {
        DB_PRINTF("[TMC2209] ERROR: %s axis connection failed! Code: %d (Check wiring/addressing)\n", axisName, result);
        return false;
    }

    // 2. Clear fault flags & configure operating mode
    driver.toff(0);                // Disable driver output during register configuration
    driver.pdn_disable(true);      // Use PDN pin exclusively for UART communication
    driver.mstep_reg_select(true); // Microsteps configured via UART registers, not hardware pins

    // 3. Set RMS active current and reduced holding current to prevent standstill overheating
    driver.rms_current(current_mA, hold_multiplier);

    // 4. Microstepping & Internal Interpolation
    driver.microsteps(STEPPER_MICROSTEPS); // 1/16 Microstepping from FastAccelStepper
    driver.intpol(true);                   // Interpolate to 1/256 internally for smooth motion

    // 5. Standstill & Powerdown Timing (drops to hold current ~0.15s after motion stops)
    driver.iholddelay(4);   // Delay before current reduction begins
    driver.TPOWERDOWN(128); // Smooth transition window to hold current
    driver.freewheel(0);    // Normal current reduction during hold

    // 6. Chopper Configuration
    driver.blank_time(24); // Comparator blank time

    if (forceSpreadCycle)
    {
        // Pure SpreadCycle (Higher torque across all speeds, but hums at standstill)
        driver.en_spreadCycle(true);
        driver.pwm_autoscale(false);
        DB_PRINTF("[TMC2209] %s Configured: %d mA RMS, Pure SpreadCycle\n", axisName, current_mA);
    }
    else
    {
        // Hybrid Mode: Silent StealthChop at standstill and low speed,
        // automatically transitions to SpreadCycle at high speed to avoid step loss.
        driver.en_spreadCycle(false); // Enable StealthChop for dead-silent standstill
        driver.pwm_autoscale(true);   // Automatically scale StealthChop voltage

        // Threshold where driver switches from StealthChop to SpreadCycle:
        // Set so standstill and low/mid speeds remain silent, while top speeds (>3000 Hz) engage SpreadCycle
        driver.TPWMTHRS(200);
        DB_PRINTF("[TMC2209] %s Configured: %d mA RMS, StealthChop Standstill + Hybrid Switch\n", axisName, current_mA);
    }

    // 7. Enable chopper
    driver.toff(4);

    // 8. Read-back register validation to ensure UART writes were latched
    uint16_t readMicrosteps = driver.microsteps();
    uint16_t readCurrent = driver.cs2rms(driver.irun());
    bool regSelectActive = driver.mstep_reg_select();

    if (!regSelectActive || readMicrosteps != STEPPER_MICROSTEPS)
    {
        DB_PRINTF("[TMC2209] ERROR: %s register read-back failed! (Microsteps: %u, RegSelect: %d)\n",
                  axisName, readMicrosteps, regSelectActive ? 1 : 0);
        return false;
    }

    DB_PRINTF("[TMC2209] %s OK: %u mA Run, %u%% Hold, %u Microsteps, RegCtrl: Verified\n",
              axisName, readCurrent, (uint16_t)(hold_multiplier * 100.0f), readMicrosteps);
    return true;
}

// Persistent state tracker per axis to manage hysteresis and single-shot stops
struct AxisControlState
{
    int lastDir = 0;          // -1 = Reverse, 0 = Stopped, 1 = Forward
    uint32_t lastSpeedHz = 0; // Last speed commanded to the driver
};

/**
 * Controls a FastAccelStepper motor smoothly using analog joystick input.
 */
void updateAxisFromJoystick(
    FastAccelStepper *stepper,
    AxisControlState &state,
    float rawInput,
    uint32_t maxSpeedHz,
    uint32_t minSpeedHz,
    float deadzone = DEADZONE_RADIUS,
    uint32_t hysteresisHz = STEPPER_HYSTERESISHZ,
    float exponent = STEPPER_EXPONENT)
{
    if (!stepper)
        return;

    float absInput = fabs(rawInput);

    // Single-Shot Stop on Deadzone Release
    if (absInput <= deadzone)
    {
        if (state.lastDir != 0)
        {
            stepper->stopMove();
            state.lastDir = 0;
            state.lastSpeedHz = 0;
        }
        return;
    }

    // Percentage of Stick Travel Past Deadzone (0.0 to 1.0)
    float normPct = (absInput - deadzone) / (1.0f - deadzone);
    if (normPct > 1.0f)
        normPct = 1.0f;

    // Exponential Response Curve
    float curvedPct = powf(normPct, exponent);

    uint32_t targetSpeedHz = (uint32_t)(curvedPct * maxSpeedHz);
    if (targetSpeedHz < minSpeedHz)
        targetSpeedHz = minSpeedHz;

    int currentDir = (rawInput > 0.0f) ? 1 : -1;

    bool dirChanged = (currentDir != state.lastDir);
    bool speedChangedSignificantly = (abs((long)targetSpeedHz - (long)state.lastSpeedHz) > (long)hysteresisHz);

    if (dirChanged)
    {
        stepper->setSpeedInHz(targetSpeedHz);
        if (currentDir > 0)
            stepper->runForward();
        else
            stepper->runBackward();
        state.lastDir = currentDir;
        state.lastSpeedHz = targetSpeedHz;
    }
    else if (speedChangedSignificantly)
    {
        stepper->setSpeedInHz(targetSpeedHz);
        stepper->applySpeedAcceleration();
        state.lastSpeedHz = targetSpeedHz;
    }
}

// ============================================================================
// Solenoid State Machine
// ============================================================================

enum SolenoidState
{
    SOLENOID_IDLE,
    SOLENOID_FIRING,
    SOLENOID_COOLDOWN
};

static SolenoidState solenoidState = SOLENOID_IDLE;
static unsigned long solenoidTimer = 0;

void triggerSolenoid()
{
    if (solenoidState == SOLENOID_IDLE)
    {
        DB_PRINTLN("[SOLENOID] Firing!");
        digitalWrite(PIN_SOLENOID, HIGH);
        solenoidTimer = millis();
        solenoidState = SOLENOID_FIRING;
    }
}

void updateSolenoid()
{
    unsigned long now = millis();

    switch (solenoidState)
    {
    case SOLENOID_FIRING:
        if (now - solenoidTimer >= SOLENOID_PULSE_LENGTH)
        {
            DB_PRINTLN("[SOLENOID] Pulse expired, turning OFF.");
            digitalWrite(PIN_SOLENOID, LOW);
            solenoidTimer = now;
            solenoidState = SOLENOID_COOLDOWN;
        }
        break;

    case SOLENOID_COOLDOWN:
        if (now - solenoidTimer >= SOLENOID_COOLDOWN_LENGTH)
        {
            DB_PRINTLN("[SOLENOID] Cooldown expired, returning to IDLE.");
            solenoidState = SOLENOID_IDLE;
        }
        break;

    case SOLENOID_IDLE:
    default:
        break;
    }
}

// ============================================================================
// Xbox Controller Processing Engine
// ============================================================================

void processXboxOverride(AxisControlState &panState, AxisControlState &tiltState)
{
    static unsigned long lastManualInputTime = 0;
    static bool lastBtnA = false;

    float rawPan = 0.0f;
    float rawTilt = 0.0f;
    float trigger = 0.0f;
    bool stickActive = false;
    bool triggerActive = false;

    xboxController.onLoop();

    if (xboxController.isConnected() && !xboxController.isWaitingForFirstNotification())
    {
        constexpr float invHalfJoy = 2.0f / (float)XboxControllerNotificationParser::maxJoy;
        constexpr float invMaxTrig = 1.0f / (float)XboxControllerNotificationParser::maxTrig;

        rawPan = ((float)xboxController.xboxNotif.joyLHori * invHalfJoy) - 1.0f;
        rawTilt = ((float)xboxController.xboxNotif.joyLVert * invHalfJoy) - 1.0f;
        trigger = (float)xboxController.xboxNotif.trigRT * invMaxTrig;

        stickActive = (fabs(rawPan) > DEADZONE_RADIUS || fabs(rawTilt) > DEADZONE_RADIUS);
        triggerActive = (trigger > TRIGGER_THRESHOLD);

        // Single-Shot 'A' Button: Zero Current Mechanical Coordinates
        bool btnAPressed = xboxController.xboxNotif.btnA;
        if (btnAPressed && !lastBtnA)
        {
            if (panStepper)
                panStepper->forceStopAndNewPosition(0);
            if (tiltStepper)
                tiltStepper->forceStopAndNewPosition(0);

            panState = AxisControlState();
            tiltState = AxisControlState();
            commandedPanSpeed = 0;
            commandedTiltSpeed = 0;
            activePanDir = 0;
            activeTiltDir = 0;
            appliedPanSpeed = 0;
            appliedTiltSpeed = 0;
            currentMotionMode = MODE_VELOCITY;

            DB_PRINTLN("[XBOX] Re-zeroed home coordinates via 'A' button.");
        }
        lastBtnA = btnAPressed;

        if (stickActive || triggerActive || btnAPressed)
        {
            lastManualInputTime = millis();
            commandedPanSpeed = 0;
            commandedTiltSpeed = 0;
            currentMotionMode = MODE_VELOCITY;
        }
    }
    else
    {
        rawPan = 0.0f;
        rawTilt = 0.0f;
        trigger = 0.0f;
        lastBtnA = false;
    }

    manualOverrideActive = (millis() - lastManualInputTime < MANUAL_OVERRIDE_TIMEOUT_MS);

    if (manualOverrideActive)
    {
        updateAxisFromJoystick(panStepper, panState, rawPan, PAN_STEPPER_MAXSPEEDHZ, PAN_STEPPER_MINSPEEDHZ);
        updateAxisFromJoystick(tiltStepper, tiltState, rawTilt, TILT_STEPPER_MAXSPEEDHZ, TILT_STEPPER_MINSPEEDHZ);

        // Manage continuous firing during manual override
        if (triggerActive)
        {
            autoFireRequested = true;
            autoFireStartTime = millis(); // Refresh timeout while trigger is physically held
        }
        else
        {
            autoFireRequested = false;
        }
    }
    else
    {
        if (panState.lastDir != 0 || tiltState.lastDir != 0)
        {
            if (panStepper && panStepper->isRunning())
                panStepper->stopMove();
            if (tiltStepper && tiltStepper->isRunning())
                tiltStepper->stopMove();
            panState = AxisControlState();
            tiltState = AxisControlState();
        }
    }
}

// ============================================================================
// Atomic Absolute Waypoint Actuation (P Command)
// ============================================================================

void commandAbsolutePositionMrad(long targetPanMrad, long targetTiltMrad)
{
    currentMotionMode = MODE_POSITION;
    commandedPanSpeed = 0;
    commandedTiltSpeed = 0;
    activePanDir = 0;
    activeTiltDir = 0;
    appliedPanSpeed = 0;
    appliedTiltSpeed = 0;

    if (panStepper)
    {
        panStepper->setSpeedInHz(PAN_STEPPER_MAXSPEEDHZ);
        long targetSteps = constrain(panMradToSteps(targetPanMrad), PAN_MIN_STEPS, PAN_MAX_STEPS);
        panStepper->moveTo(targetSteps);
    }

    if (tiltStepper)
    {
        tiltStepper->setSpeedInHz(TILT_STEPPER_MAXSPEEDHZ);
        long targetSteps = constrain(tiltMradToSteps(targetTiltMrad), TILT_MIN_STEPS, TILT_MAX_STEPS);
        tiltStepper->moveTo(targetSteps);
    }
}

// ============================================================================
// Continuous Dynamic Velocity Slew Actuation (V Command)
// ============================================================================
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
void loop()
{
    static AxisControlState panState;
    static AxisControlState tiltState;
    static unsigned long lastTelemetryTime = 0;

    // Periodic check to restore register configuration if TMC2209 brownout reset occurred
    static unsigned long lastDriverCheck = 0;
    if ((millis() - lastDriverCheck >= 3000) && !panStepper->isRunning() && !tiltStepper->isRunning())
    {
        lastDriverCheck = millis();

        if (!panTMC.mstep_reg_select() || panTMC.microsteps() != 16 ||
            !tiltTMC.mstep_reg_select() || tiltTMC.microsteps() != 16)
        {
            DB_PRINTLN("[TMC2209] Driver reset detected! Re-applying UART parameters...");
            initTMC2209(panTMC, "PAN", 1200, 0.25f);
            initTMC2209(tiltTMC, "TILT", 1100, 0.15f);
        }
    }

    // 1. Process Xbox Controller Input & Manual Overrides
    processXboxOverride(panState, tiltState);

    // 2. Process Incoming Host Serial Commands
    processSerialCommands();

    // 3. Failsafe Watchdog: Prevent runaway motion if serial link is lost
    if ((millis() - lastSerialRxTime > SERIAL_WATCHDOG_TIMEOUT_MS) && !manualOverrideActive)
    {
        if (currentMotionMode == MODE_VELOCITY && (commandedPanSpeed != 0 || commandedTiltSpeed != 0))
        {
            commandedPanSpeed = 0;
            commandedTiltSpeed = 0;
            if (panStepper)
                panStepper->stopMove();
            if (tiltStepper)
                tiltStepper->stopMove();
        }

        if (autoFireRequested)
        {
            autoFireRequested = false;
        }
    }

    // 4. Autonomous Tracking Actuation
    if (!manualOverrideActive)
    {
        applyVelocityActuation();
    }

    // 5. Autonomous Firing Logic
    if (autoFireRequested)
    {
        if (millis() - autoFireStartTime >= MAX_AUTONOMOUS_FIRE_DURATION_MS)
            autoFireRequested = false;
        else
            triggerSolenoid();
    }

    // 6. Update Solenoid Actuator Timing
    updateSolenoid();

    // 7. Broadcast Telemetry to Raspberry Pi at 20 Hz (every 50 ms) in milliradians
    unsigned long now = millis();
    if (now - lastTelemetryTime >= 50)
    {
        lastTelemetryTime = now;
        long currentPanSteps = panStepper ? panStepper->getCurrentPosition() : 0;
        long currentTiltSteps = tiltStepper ? tiltStepper->getCurrentPosition() : 0;
        bool isMoving = (panStepper && panStepper->isRunning()) || (tiltStepper && tiltStepper->isRunning());
        bool firingActive = (autoFireRequested || solenoidState != SOLENOID_IDLE);

        Serial.printf("S %lu %ld %ld %d %d\n",
                      now,
                      panStepsToMrad(currentPanSteps),
                      tiltStepsToMrad(currentTiltSteps),
                      firingActive ? 1 : 0,
                      isMoving ? 1 : 0);
    }
}

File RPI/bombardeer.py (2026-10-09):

#!/usr/bin/env python3
"""
Bombardeer Turret: Real-Time Dual-Mode Controller (Mission-Critical Edition)
----------------------------------------------------------------------------
- Architecture:
    * Asynchronous Perception & Motion Decoupling:
        - Vision Worker: Processes frames at sensor/inference rate (15-30 Hz).
        - Motion Servoing Loop: Runs deterministically at 50 Hz (20ms ticks),
          predicting target state and feeding the ESP32 continuous velocity
          vectors regardless of optical frame cadence or ML inference lag.
    * Concurrency Architecture (Segregated Lock Planes):
        - telemetry_lock: High-speed motor angles, moving flags, and history deque.
        - target_lock: Perception target state, supervisory health, and storage metrics.
        - frame_lock: Flask JPEG streaming and client tracking.
        - mode_lock: Tri-state engagement model (OFF -> ON -> ARMED / CALIBRATE).
    * Latency-Compensated Time-Sync Forward Projection:
        - Projects Kalman state to the exact actuation instant, eliminating
          hunting, overshoot, and FastAccelStepper trajectory replanning halts.
    * 1.5-Second Continuous Dead-Reckoning Coasting:
        - Exponential velocity decay through optical dropouts, foliage
          occlusions, and motion blur without resetting filter momentum.
    * Software Travel Clamping & Angular Velocity Fire Gating:
        - Prevents driving into mechanical stops and suppresses firing during
          high-speed slewing.
    * Clamped Multithreading & Zero-Copy Communications:
        - Binary UART protocol at 921,600 baud with non-blocking supervisor.
"""

import os
os.environ["LIBCAMERA_LOG_LEVELS"] = "IPARPI:FATAL"

import glob
import time
import math
import shutil
import datetime
import threading
import queue
import logging
import traceback
from collections import deque
import numpy as np
import cv2
import serial
from flask import Flask, Response, render_template_string, jsonify, request, send_from_directory

from picamera2 import Picamera2
from libcamera import Transform

# -------------------------------------------------------------------------
# OpenCV Deterministic Core Clamping
# -------------------------------------------------------------------------
# Clamp OpenCV to 2 worker threads on physical cores 0 & 1, leaving cores
# 2 & 3 dedicated to the 50 Hz motion servo, UART I/O, and PiSP DMA interrupts.
cv2.setNumThreads(2)
cv2.ocl.setUseOpenCL(False)

# =========================================================================
# Structured Logging Setup
# =========================================================================

logging.basicConfig(
    level=logging.INFO,
    format="%(asctime)s.%(msecs)03d [%(levelname)s] %(message)s",
    datefmt="%H:%M:%S"
)
log = logging.getLogger("Bombardeer")

# =========================================================================
# Configuration & Hardware Calibration
# =========================================================================

BASE_DIR = os.path.dirname(os.path.abspath(__file__))
STATIC_DIR = os.path.join(BASE_DIR, "static")
RECORDINGS_DIR = os.path.join(BASE_DIR, "recordings")

try:
    os.makedirs(RECORDINGS_DIR, exist_ok=True)
    test_touch = os.path.join(RECORDINGS_DIR, ".write_test")
    with open(test_touch, "w") as f:
        f.write("ok")
    os.remove(test_touch)
    log.info(f"[STORAGE] Storage directory verified writable: {RECORDINGS_DIR}")
except Exception as e:
    log.error(f"[STORAGE ERROR] Cannot write to storage path {RECORDINGS_DIR}: {e}")

FRAME_WIDTH = 1280
FRAME_HEIGHT = 720
DISPLAY_WIDTH = 640
DISPLAY_HEIGHT = 360

SCALE_X = DISPLAY_WIDTH / FRAME_WIDTH
SCALE_Y = DISPLAY_HEIGHT / FRAME_HEIGHT
OPTICAL_CENTER = (FRAME_WIDTH // 2, FRAME_HEIGHT // 2)

# --- PHYSICAL PARALLAX OFFSETS (Camera relative to Barrel) ---
CAMERA_OFFSET_X_MM = -170.0  # Camera 170mm Left of Bore
CAMERA_OFFSET_Y_MM = -60.0   # Camera 60mm Below Bore

# Camera Optical Intrinsics
FOCAL_LENGTH_PX = 540.4
MRAD_PER_PIXEL_X = 1000.0 / FOCAL_LENGTH_PX
MRAD_PER_PIXEL_Y = 1000.0 / FOCAL_LENGTH_PX

ARUCO_REAL_WIDTH_MM = 365.0
MIN_VALID_RANGE_M = 3.0
MAX_VALID_RANGE_M = 75.0

# Dynamic Targeting, Hysteresis & Deadbands
BALLISTIC_ACQUIRE_MRAD = 120.0     # Snap-to-target threshold from rest
BALLISTIC_ABORT_MRAD = 260.0       # Only abort velocity mode if target exceeds 260mrad
VELOCITY_DEADBAND_MRAD = 4.0       # Coast to standstill inside this error radius
FIRE_DEADBAND_MRAD = 40.0          # Permissive firing engagement radius
MAX_FIRE_SLEW_SPEED_MRAD_S = 180.0 # Suppress firing if turret is slewing faster than this
MOTION_LOOP_INTERVAL_SEC = 0.020   # 50 Hz deterministic motion servo loop
SETPOINT_MIN_INTERVAL_SEC = 0.040  # 25 Hz maximum UART transmission rate

# Software Travel Limits (Physical Axis Protection)
TILT_MIN_MRAD = -420
TILT_MAX_MRAD = 400

MAX_TRIGGER_DURATION_SEC = 2.0
TRIGGER_COOLDOWN_SEC = 1.5

TARGET_MARKER_ID = 0
CONFIRMATION_FRAMES = 2

# Persistence & Coasting Horizons
COAST_MAX_HORIZON_SEC = 1.500      # Track through occlusions up to 1.5s
COAST_EXP_DECAY_RATE = 2.5         # Exponential velocity decay factor after 350ms

DEFAULT_SERIAL_PORTS = ["/dev/ttyUSB0", "/dev/ttyACM0", "/dev/ttyUSB1"]
BAUD_RATE = 921600
SERIAL_HEARTBEAT_TIMEOUT_SEC = 2.5

TARGET_FPS = 30.0
RECORD_PRE_ROLL_SEC = 2.0
RECORD_POST_ROLL_SEC = 3.0
MIN_LOCK_FRAMES_TO_RECORD = 3
MAX_RECORDING_DURATION_SEC = 30.0

MIN_FREE_SPACE_GB = 5.0
MAX_RECORDINGS_STORAGE_GB = 10.0

STREAM_PART_HEADER = b"--frame\r\nContent-Type: image/jpeg\r\n\r\n"
STREAM_PART_FOOTER = b"\r\n"

# =========================================================================
# Concurrency Architecture: Isolated Lock Planes
# =========================================================================
app = Flask(__name__)

# Lock 0: Operational Engagement (OFF, ON, ARMED, CALIBRATE)
mode_lock = threading.Lock()
turret_mode = "OFF"       # Power-on state is always disarmed and inert
calibrate_primed = False  # Single-shot authorization token for calibration

def get_turret_mode():
    with mode_lock:
        return turret_mode, calibrate_primed

def set_turret_mode(new_mode, primed=None):
    global turret_mode, calibrate_primed
    with mode_lock:
        turret_mode = new_mode
        if primed is not None:
            calibrate_primed = primed
        elif new_mode == "CALIBRATE":
            calibrate_primed = True  # Auto-prime on entering calibration mode
        elif new_mode in ("OFF", "ON"):
            calibrate_primed = False

def consume_calibration_prime():
    """Atomically consumes the single-shot calibration authorization token."""
    global calibrate_primed
    with mode_lock:
        if calibrate_primed:
            calibrate_primed = False
            return True
        return False

# Lock 1: Web Streaming Buffer and Client Counter
frame_lock = threading.Lock()
latest_jpeg = None
active_web_clients = 0
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

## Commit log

2026-08-10 Bombadeer is an autonomous, vision-guided deterrent turret designed to protect outdoor spaces from intrusive wildlife (such as deer). Powered by a **Raspberry Pi 5** with a **26 TOPS Hailo AI acceler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
    Initial commit to setup project and add basic Xbox controller support.
    [top_worm_gear.scad]
2026-08-10 Add initial stepper motor speed and acceleration settings for pan and tilt axes. Adjusted the speed and acceleration values to optimize performance.
    [top_worm_gear.scad]
2026-08-11 Update GPIO pin definitions to match the V1 hardware we're using
    Update the Xbox control logic to:
    1) have a deadzone to prevent movement when the stick is centered
    2) have an exponential response curve for low speed precision
    3) do hysteresis filtering to minimize driver updates as they cause stutter
    4) on reentering the deadzone, have a single call to "stopMove" so FastAccelStepper can smoothly decelerate to 0
    [2020 T-Slot Extrusion to 8mm Metal Rod End-Mount Adapter (Cylindrical).scad, Skeletonized wedge with worm gear.scad]
2026-08-11 Remove old battery and LED logic as it doesn't exist in this version of the hardware. Update README.md to remove references to the old battery and LED logic.
    [main.cpp]
2026-08-11 Update trigger solenoid logic to prevent overlapping triggers and ensure proper timing without using a blocking call to delay().
    [main.cpp]
2026-08-14 Update the "T-Slot to 9mm rod adapter" to no longer use an M5 bolt through the end into the T-slot 2020 and instead have a counterbore screw on the side and use standard t-slot hardware to connect it.
    Update the worm gear to have a set screw hole centered on the NEMA 17
    D-Shaft to hold it in place
    Update stepper motor acceleration and speed limits to reflect the new
    STEPPERONLINE 17HS19-2004S motors
    [2020 T-Slot Extrusion to 8mm Metal Rod End-Mount Adapter (Cylindrical).scad, top_worm_gear.scad]
2026-08-19 Add the OpenSCAD files for the Lazy Susan ring gear and the Spyder Victor mount.
    Update the main.cpp file to use a better top speed and ramp for the new stepper motors.
    [lazy_susan_ring_gear_hollow.scad, spyder_victor_turret_mount.scad]
2026-08-24 Implement auto-fire feature with a non-blocking 3-state machine (IDLE, FIRING, COOLDOWN) for solenoid control to enable rapid-fire while preventing coil overheat and sear-skip. Currently set to 4 sho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
    Configure TMC2209 drivers for hybrid mode using StealthChop at standstill/low speeds to eliminate idle hum, dynamically switching to SpreadCycle at high velocity via TPWMTHRS
    Standardize driver initialization registers (`toff`, `pdn_disable`, `freewheel`) for deterministic holding current behavior across boots.
    Tune the top speed and acceleration separately for pan and tilt.
    Update 3D printed Lazy Susan ring and pinion set for new 6" lazy Sus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
    [17HS19-2004S1.STEP, lazy_susan_ring_gear_hollow.scad, spyder_victor_turret_mount.scad]
2026-09-02 Big update: compile MDV6-yolov9-c for Hailo-8 and deploy live tracking on RPi 5
    - Quantized and compiled Microsoft MegaDetector v6 (YOLOv9-c) to a 4-context
    HEF binary using Hailo AI Software Suite with GPU acceleration in WSL2.
    - Integrated Picamera2 with HailoRT on Raspberry Pi 5 to stream zero-copy
    640x640 RGB frames directly into the NPU.
    - Implemented multi-scale DFL and classification decoding to track animal
    detections and calculate optical center displacement errors (dx, dy).
    - Upgraded RPi 5 PCIe link to Gen 3 (8 GT/s), achieving ~24.66 FPS sustained
    throughput at 37.7 ms hardware latency.
    - Added Flask-based MJPEG live HUD web stream with reticle and tracking vectors.
    - Con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
    [17HS19-2004S1.STEP, 2020 T-Slot Extrusion to 8mm Metal Rod End-Mount Adapter (Cylindrical).scad, 2020 T-Slot Extrusion to 8mm Metal Rod End-Mount Adapter (Cyli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]
2026-09-11 bombardeer.py uses a standard Aruco Target to make target detection reliable and testable.
    Update ESP32 to support new serial interface with all units in mrads.
    Make TMC2209 more robust by:
    1) reading values after setting them to determine if they are correct and
    2) detecting if the settings are wrong and correcting them in loop()
    Add/rename openscad files for camera mount and pan/tilt gears.
    [Skeletonized wedge with worm gear.stl, camera_mount.scad, camera_mount.stl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]
2026-09-26 Integrate mrad kinematics, camera parallax compensation. Add new SCAD/STL models for camera mount and pan timing gears to reduce backlash. Add calibration utilities used to determine physical mountin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
    - Firmware (ESP32 / src/main.cpp, platformio.ini):
    * Migrate communication and motion control to native milliradian (mrad / mrad/s) kinematics.
    * Refactor Xbox controller handling into dedicated processXboxOverride() function with clean fail-safes and manual override timeout gating.
    * Add single-shot 'A' button action to instantly zero mechanical coordinates across both axes.
    * Update timing and tuning constants to measured values.
    - V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
    [camera_mount.scad, camera_mount.stl, pan_timing_gears.scad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]
2026-09-28 Update the bombardeer.py script to uses the correct color model for the camera and processes the images without unnecessary conversions, improving performance and accuracy.
    Also update the script to better estimate range based on the camera's
    measured characteristics and the target's size, providing more reliable
    distance calculations.
    [bombardeer.py]
2026-09-29 feat(tracking): achieve single-stroke target acquisition
    - Implement a 4-state constant-velocity Kalman filter in world milliradian space
    to eliminate sub-pixel detection jitter, range noise, and standstill hunting.
    - Synchronize host/controller serial links to 921,600 baud across main.cpp
    and bombardeer.py, preventing framing errors.
    - Fix serial buffer bloat in bombardeer.py by replacing line-by-line reads
    with a non-blocking chunk burst drainer, reducing telemetry RTT from ~1000ms
    down to ~2.2ms.
    - Replace linear small-angle pixel scaling with true pinhole projection
    (math.atan2), eliminating 60+ mrad wide-angle peripheral lens distortion.
    - Add system architecture specification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
    [bombardeer.py, calibrate_optics.py, calibrate_stepper_limits.cpp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]
2026-09-29 Implement dual-mode tracking with fluid velocity pursuit
    - Implement hybrid dual-mode motion control architecture:
    * Mode 1 (Ballistic Intercept): Use absolute waypoint commands ('P') for
    large initial displacements (>65 mrad) to execute full-acceleration
    single-stroke target acquisition.
    * Mode 2 (Fluid Pursuit): Stream proportional continuous velocities ('V')
    for displacements <=65 mrad, eliminating FastAccelStepper standstill
    deceleration shudders and stick-slip hunting on moving targets.
    - Tune proportional pursuit gain to Kp = 2.8 and expand ballistic boundary to
    65 mrad, eliminating steady-state lag and preventing mid-traverse mode collisions.
    - Handle continuous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
    [bombardeer.py]
2026-10-01 Update our motion tracking logic: isolate concurrency planes, prevent setpoint flooding, and gate solenoid firing
    - Restructure concurrency into three distinct lock domains (telemetry_lock, target_lock, frame_lock) to eliminate lock contention and priority inversion between the 50 Hz motion servo and 921.6k baud UART RX worker.
    - Encapsulate hardware state inside a structured turret_telemetry container with atomic update accessors and a get_instantaneous_telemetry() snapshot helper.
    - Eliminate Mode 1 ('P') waypoint flooding by enforcing a 400 ms rate limit and a 60 mrad goal delta gate during ballistic moves.
    - Enhance Mode 2 ('V') velocity pursuit with 1.0x target feed-forward and retuned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
    [bombardeer.py, main.cpp]
2026-10-04 Add projectbox.scad and projectbox.stl for 3D printing a box to hold the RPI and turret electronics.
    Bug fixes:
    bombardier.py:
    - Replace hardcoded paths (/home/ben/bombardier/status) with relative paths (status) on the RPI
    - Drain multiple velocity commands in turret_serial_worker and only keep the latest
    - Remove unnecessary float math in applyVelocityActuation()
    main.cpp
    - Harden processSerialCommands() against invalid or corrupt command strings.
    - Only check TMC2209 configuarion in loop() when the motors aren't running.
    - Allow MODE_POSITION commands to complete and not get canceled after SERIAL_WATCHDOG_TIMEOUT_MS.
    [projectbox.scad, projectbox.stl]
2026-10-06 Add error logging to detect/report inability to connect to the ESP32 via serial
    Pre-allocate a fixed ring buffer for video pre-roll
    Update vision_thread() to seamlessly utilize the pre-roll buffer without any unnecessary copies
    Update the Web UI to be more mobile friendly and add a 'full screen' option
    [bombardeer.py]
2026-10-06 Add much more ventilation to the project box.
    [projectbox.scad, projectbox.stl]
2026-10-08 Add a tri-state engagement switch to the bombardeer. This allows the user to select between three modes of operation: "Off", "On", and "Armed". The "Off" mode disables the bombardeer tracking and fir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
2026-10-09 Enable continuous firing during manual override with the xbox trigger.
    Add a "calibrate" mode that requires you to press '1-shot' to fire, and
    will not allow continuous firing. This is useful for testing the camera
    detection and firing logic.
